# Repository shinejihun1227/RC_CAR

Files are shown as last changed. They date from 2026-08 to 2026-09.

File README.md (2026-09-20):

# RC_CAR · ESP32 RC카 강의 실습

기본 모터 주행부터 거리 감지, 무선 조종, 손 제스처, 2구동륜 PID 속도 제어까지 직접 구현하는 강의용 저장소입니다. **ESP32에 Arduino IDE로 코드를 업로드하고, C언어 문법 중심으로 실습합니다.** 수업에 필요한 코드·배선·부품·설계를 모았습니다.

학생이 작성하는 제어 로직은 변수, 조건문, 반복문, 함수, 배열, 구조체로 구성합니다. `.ino`는 C++로 컴파일되며 `Serial`, `Wire`, 센서 객체는 Arduino 라이브러리의 API를 사용합니다. [C언어 중심 실습 안내](course/ARDUINO_C_GUIDE.md)에서 이 구분과 단계별 과제를 확인합니다.

## v0~v4에서 배우는 것

| 단계 | 결과물 | 코딩 개념 | 주요 부품·하드웨어 |
|---|---|---|---|
| [v0 기본 주행](v0/README.md) | 시리얼 명령으로 움직이는 2WD RC카 | 상수, 함수, 조건문, GPIO, PWM, 시리얼 입력 | ESP32, TB6612FNG 1개, TT 모터 2개 |
| [v1 거리 안전](v1/README.md) | 가까운 장애물 앞에서 전진을 멈추는 차량 | I²C, 라이브러리, 임계값, 상태와 반복 감시 | v0 + VL53L1X |
| [v2 무선 조종](v2/README.md) | 조이스틱으로 제어하는 무선 RC카 | ADC, 데드존, 값 변환, 구조체, 콜백, ESP-NOW | 조종기 ESP32, 조이스틱, 정지 버튼 추가 |
| [v3 제스처 조종](v3/README.md) | 손 기울기로 제어하는 차량 | Roll/Pitch 계산, 평균 보정, 입력 장치 교체 | 조종기에 BMI270 추가, v2 수신기 재사용 |
| [v4 2구동륜 속도 제어](v4/README.md) | 좌우 구동륜 RPM을 보정하고 뒤 수동 바퀴가 따라오는 차량 | 인터럽트, 펄스·RPM, 배열, 시간 간격, PID | 엔코더 N20 2개, 수동 바퀴 2개, TB6612FNG 1개 |

v0~v3은 TT 모터 2개로 기능을 익힙니다. v4에서는 좌우 N20 엔코더 모터 2개와 뒤쪽 수동 바퀴 2개로 구동계를 바꾸며 차량 핀맵도 바뀝니다. v4는 v2 조이스틱 조종기 또는 v3 제스처 조종기를 사용할 수 있습니다.

## 수업 시작

1. [전체 학습 흐름](course/README.md), [C언어 중심 실습 안내](course/ARDUINO_C_GUIDE.md), [설치·업로드 준비](course/setup/README.md)를 확인합니다.
2. [전체 부품표](parts/BOM.md)에서 해당 단계의 부품을 준비합니다.
3. v0부터 README, 배선표, 단품 테스트, 통합 코드를 순서대로 진행합니다.
4. [장비별 설정](course/CONFIGURATION.md)에 따라 MAC 주소, 모터 방향, 엔코더 펄스 수를 설정합니다.
5. [실습 기록 양식](course/LAB_RECORD.md)에 측정값과 결과를 기록합니다.

## 폴더 안내

```text
RC_CAR/
├─ v0/ ... v4/       단계별 설명·배선·시험 절차·Arduino 코드
├─ course/           전체 학습 흐름·설치·설정·실습 기록
├─ parts/            부품 역할·원리·전체 BOM·구매 규격
└─ hardware/         Fusion 360 설계 코드·참조 부품·STL
```

| 자료 | 용도 |
|---|---|
| [부품과 신호](parts/README.md) | ESP32·드라이버·모터·센서의 역할 |
| [부품 작동 원리](parts/PRINCIPLES.md) | 전원, H-브리지·PWM, ToF, IMU, 엔코더·PID |
| [Fusion 360·STL](hardware/README.md) | 실물 치수 확인과 차체·조종기 설계 |
| [Arduino C 실습](course/ARDUINO_C_GUIDE.md) | C 문법 학습 순서·코드 읽기·수정 과제·시리얼 확인 |

차량 전원은 1.5V AA 알카라인 4개(공칭 6V)와 ESP32용 5V 벅-부스트를 기준으로 합니다. 조종기 전원은 1셀 배터리를 보호·충전 회로와 3.3V 정전압 레귤레이터를 거쳐 공급합니다. 모터 전원과 로직 전원을 구분하고 각 장치 안에서 GND를 공통으로 연결합니다. 처음 모터를 시험할 때는 바퀴를 바닥에서 띄웁니다.

## 게시 범위

GitHub에는 강의에서 직접 사용하는 Arduino 코드·배선·부품·설계를 게시합니다. PPT·한글 문서, PC용 Python 시리얼 실습과 제작 중간 자료는 로컬에서 관리합니다. Fusion 360용 Python 생성기는 차체 설계 도구로 유지합니다. 이후에도 적용할 기준은 [AGENTS.md](AGENTS.md)에 기록합니다.

MAC 주소, 엔코더 PPR, PID 계수와 설계 치수는 장비에 맞춰 확인해야 합니다. 컴파일 확인과 실물 주행 시험은 별도로 기록합니다.

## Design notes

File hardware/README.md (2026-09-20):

# 차체·조종기 설계 실습

실제 부품을 측정하고 샤시·브래킷·배터리·전자부품의 장착 공간을 확인하는 자료다. 설계 코드가 실행되는 것과 실물에 맞는 것은 별도로 확인한다.

v4 모터 장착·부품 배치 실습은 좌우 N20 2구동륜과 뒤 수동 바퀴 2개를 기준으로 [실측 부품 기반 Fusion 360 설계 안내](fusion360/MEASURED_PARTS_WORKFLOW.md)에서 시작한다. 불러올 부품별 파일, STEP/STL 선택, 실측 기록, 파라미터와 출력 여유, 시험 출력 순서를 정리했다.

| 수업 | 파일 | 용도 |
|---|---|---|
| 기본 샤시 | [기본 프레임 생성기](fusion360/RC_CAR_Chassis_Frame_Builder.py) | 300×400mm 샤시, 레일, 범퍼, 브리지. [설명](fusion360/CHASSIS_ONLY_README.md) |
| 부품 장착 | [장착 프레임 생성기](fusion360/RC_CAR_Mounting_Frame_Builder.py) | N20 브래킷, 배터리 트레이, 전장 데크, ToF 장착부 |
| 로버형 확장 | [로버 샤시 생성기](fusion360/RC_CAR_Rover_Chassis_Builder.py) | 320×420mm 차체·상부 데크·작업 장치 인터페이스. [설명](fusion360/ROVER_CHASSIS_README.md) |
| 부품 배치 | [참조 부품](reference-parts/README.md) | 모터·바퀴·보드·홀더 외곽 STL와 배치 생성기 |
| 조종기·모터 고정 | [STL 안내](stl/README.md) | 케이스 상·하판과 N20 마운트 |

## 실행 순서

1. 실제 모터·축·장착홀, 보드 USB 위치, 배터리 홀더를 캘리퍼스로 측정한다.
2. Fusion 360의 Scripts and Add-Ins에서 필요한 Python 생성기를 등록·실행한다.
3. 새 Design에서 컴포넌트와 파라미터를 확인한다.
4. 브래킷 또는 홀 시편부터 시험 출력한다.
5. 간섭과 체결을 확인한 뒤 전체 차체에 적용한다.

현재 대형 프레임은 220×220mm급 프린터보다 크다. 프린터에 맞는 크기 변경·분할 등 제작 방식을 먼저 정한다. v0~v3의 소형 TT 실습에 대형 로버 프레임이 필수인 것은 아니다.

장착 프레임은 앞쪽 좌우 N20 브래킷을 기본 표시하고 뒤쪽 수동 바퀴 지지 구역을 별도로 두며 TT 브래킷과 참조 외곽을 숨기는 구성이다. v4에서 모터를 교체할 때 엔코더 PCB·배선 공간과 수동 바퀴의 접지 높이를 확인한다.

[치수 출처와 확인 항목](fusion360/DIMENSION_SOURCES.md)

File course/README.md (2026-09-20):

# 전체 강의 흐름

Arduino IDE에서 C언어 문법 중심으로 코딩하고 ESP32에서 실행한다. 한 단계에서 입력·판단·출력을 이해한 뒤, 다음 단계에서 입력 장치나 피드백을 하나씩 확장한다. [C 문법·수정 과제 안내](ARDUINO_C_GUIDE.md)를 함께 사용한다.

| 단계 | 수업에서 설명할 내용 | 핵심 코드 읽기 | 하드웨어 실습 | 학생 결과물 |
|---|---|---|---|---|
| [v0](../v0/README.md) | ESP32가 방향 신호와 PWM을 만들고 드라이버가 모터를 구동하는 과정 | int, const, 함수·인자, if, switch, setup/loop, GPIO·PWM | 공통 GND, 좌우 모터 연결과 방향 확인 | 시리얼 f/b/l/r/s 주행 |
| [v1](../v1/README.md) | 거리를 숫자로 읽고 전진 허용 여부를 판단하는 과정 | Wire, 센서 초기화, 조건식, millis, 현재 명령 상태 | SDA/SCL과 센서 전원, 거리별 측정 | 20cm 이하 전진 정지 시험 |
| [v2](../v2/README.md) | 조종기 입력을 명령 패킷으로 바꿔 차량에 전달하는 과정 | analogRead, map, 데드존, struct, callback, 시간 초과 | ESP32 2개, 조이스틱, 정지 버튼 | 무선 조종·통신 끊김 정지 시험 |
| [v3](../v3/README.md) | 가속도로 기울기를 추정하고 같은 패킷으로 보내는 과정 | atan2, sqrt, 평균, 중립 오프셋, 각도→명령 변환 | BMI270 I²C 배선과 장착 방향 | 중립·전후·좌우 제스처 시연 |
| [v4](../v4/README.md) | 좌우 구동 모터의 명령과 실제 회전 속도 차이를 보정하는 과정 | ISR, volatile, 임계 구역, 배열, dt, P/I/D | 좌우 모터 독립 구동, CHA 2개, 뒤 수동 바퀴, PPR 실측 | 좌우 RPM 기록·직진 편차 비교 |

## 수업 진행 방식

1. 부품 하나의 역할과 신호를 설명한다.
2. 전원을 끈 상태에서 배선하고 단품 읽기/구동 코드를 업로드한다.
3. 시리얼 출력과 실제 동작을 비교한다.
4. 기존 동작에 새 기능을 연결한다.
5. 실패 상황도 시험하고 결과를 기록한다.

v0의 간단한 주행이 v1의 안전 판단을 이해하는 출발점이다. v2에서는 입력이 PC에서 무선 조종기로 바뀐다. v3는 차량을 바꾸기보다 조종기 입력을 교체하는 실습이다. v4는 차량 구동계와 제어 방식을 바꾸는 단계다.

## 공통 준비

- [설치·업로드](setup/README.md)
- [장비별 설정값](CONFIGURATION.md)
- [부품표](../parts/BOM.md)와 각 버전의 배선표
- [실습 기록](LAB_RECORD.md)
- [샤시 설계](../hardware/README.md): 실제 부품 외곽과 장착홀을 측정한 뒤 진행

## Arduino 시리얼 모니터로 확인하기

아래 실습은 Arduino IDE의 시리얼 모니터를 115200 baud로 열어 진행한다. 별도 PC 프로그램 설치 없이 센서 값과 명령을 확인한다.

| 연결 단계 | 업로드할 Arduino 스케치 | 확인할 내용 |
|---|---|---|
| v1 거리 단품 | [01_distance_read](../v1/firmware/01_distance_read/01_distance_read.ino) | distance_mm 값과 실제 거리 비교 |
| v1 안전 주행 | [02_safety_stop](../v1/firmware/02_safety_stop/02_safety_stop.ino) | 입력창에서 f/b/l/r/s를 전송하고 전진 정지 확인 |
| v3 센서 단품 | [00_bmi270_read](../v3/firmware/00_bmi270_read/00_bmi270_read.ino) | 가속도·자이로 값의 축과 단위 |
| v3 제스처 판정 | [01_gesture_map_test](../v3/firmware/01_gesture_map_test/01_gesture_map_test.ino) | Roll/Pitch와 STOP/FORWARD/BACKWARD/LEFT/RIGHT |
| v4 엔코더 단품 | [00_encoder_read](../v4/firmware/00_encoder_read/00_encoder_read.ino) | 좌우 구동륜의 펄스 수와 RPM 기록 |
| v4 PID 조정 | [01_speed_pid_tune](../v4/firmware/01_speed_pid_tune/01_speed_pid_tune.ino) | f/b/s와 +/- 명령으로 목표 RPM과 실제 RPM 비교 |

v3 제스처 판정 단품은 원시 가속도로 각도를 계산한다. v3 통합 조종기는 부팅 시 100회 평균으로 중립을 보정하므로 둘의 출력 기준을 구분해서 설명한다. 측정값은 [실습 기록](LAB_RECORD.md)에 적는다.

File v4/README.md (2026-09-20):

# v4 · 엔코더 N20 2구동륜 PID 제어

좌우 N20 엔코더 모터 2개의 회전 속도를 측정하고 목표 RPM과의 차이를 PWM으로 보정한다. 뒤쪽 2바퀴는 자유회전 수동 바퀴다.

## 배우는 코딩

Arduino IDE에서 C 문법 중심으로 진행한다. [단계별 문법·수정 과제](../course/ARDUINO_C_GUIDE.md)를 함께 사용한다.

인터럽트에서 좌우 CHA 상승 에지를 센다. 임계 구역으로 카운터를 복사하고 펄스 수·측정 시간·PPR로 RPM을 계산한다. 배열과 반복문으로 구동 모터 2개를 처리하며 P/I/D와 trim으로 출력을 보정한다. 수동 바퀴에는 모터나 엔코더를 연결하지 않는다. 엔코더는 CHA만 읽으므로 회전 방향을 직접 측정하지 않는다.

## 하드웨어와 부품

엔코더 N20 2개, 자유회전 수동 바퀴 2개, N20 브래킷 2개, TB6612FNG 1개를 사용한다. VL53L1X와 조종기는 재사용한다. v0 핀맵을 그대로 쓰지 않는다. GPIO 34/35는 엔코더 입력이며 필요한 경우 외부 풀업을 사용한다.

[배선표](docs/wiring.md) · [전원 시스템 검토](docs/power-analysis.md) · [단계별 부품표](docs/bom.md) · [구매 규격](../parts/purchasing/v4.md) · [부품 원리](../parts/PRINCIPLES.md)

차체와 모터 마운트는 [실측 부품 기반 Fusion 360 설계 안내](../hardware/fusion360/MEASURED_PARTS_WORKFLOW.md)에 따라 부품 외곽·축·장착홀을 확인하고 한 개를 시험 출력한 뒤 제작한다.

## 실습 순서

[설치 안내](../course/setup/README.md)를 확인하고 표의 순서대로 각 스케치를 별도로 업로드한다.

| 스케치 | 실습 내용 |
|---|---|
| [00_encoder_read](firmware/00_encoder_read/00_encoder_read.ino) | 좌우 구동륜 펄스·RPM, 출력축 PPR 실측 |
| [01_speed_pid_tune](firmware/01_speed_pid_tune/01_speed_pid_tune.ino) | f/b/s와 +/-로 목표 RPM·PID 시험 |
| [vehicle_encoder_receiver](firmware/vehicle_encoder_receiver/vehicle_encoder_receiver.ino) | v2 또는 v3 조종기·전진 거리 정지·좌우 2모터 PID 통합 |

[PID 튜닝 순서](docs/pid-tuning.md)를 따르고, 튜닝 코드에서 확인한 PPR·PID·trim 값을 통합 수신기에도 반영한다.

## 확인할 결과

세 스케치의 PPR 기본값 1.0을 좌우 구동륜 실측값으로 바꾼다. 바퀴를 띄워 방향·RPM을 확인하고 저속 직진 편차를 비교한다. PID·trim 기본값은 실물 튜닝 완료값이 아니다. 수동 바퀴가 바닥에 고르게 닿고 구동 바퀴와 같은 접지 높이를 갖는지 별도로 확인한다.

[요구사항](docs/requirements.md) · [시험 절차](docs/test-plan.md) · [장비 설정](../course/CONFIGURATION.md) · [실습 기록](../course/LAB_RECORD.md)

## 다음 단계

CHB 방향 측정, 속도 기록, 주행 편차 분석을 선택 확장으로 진행한다.

[전체 학습 흐름](../course/README.md)

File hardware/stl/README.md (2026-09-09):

# 조종기·모터 장착 STL

| 파일 | 사용하는 실습 | 확인할 것 |
|---|---|---|
| [controller-top.STL](controller-top.STL) | v2 조이스틱 조종기 케이스 상판 | 조이스틱·버튼 구멍, ESP32 USB 공간 |
| [controller-bottom.STL](controller-bottom.STL) | v2 조종기 케이스 하판, v3 배치 검토 | 보드 고정·배선·BMI270 추가 공간 |
| [N20withEncoder_mount.stl](N20withEncoder_mount.stl) | v4 N20 모터 장착 | 모터 폭·고정홀·엔코더 PCB·축 높이 |

기존 강의 작업 폴더에 보관되어 있던 파일이다. 부품 모델명과 실제 치수를 대조하고 한 개를 시험 출력한 뒤 적용한다. 참조 부품 폴더의 외곽 STL는 이 파일들과 용도가 다르다.

외부 모델을 사용할 때는 원 출처의 사용 조건을 따른다. 기존 프로젝트의 조종기 참고 출처는 [Wallieonline ESP-NOW 조종기](https://www.wallieonline.nl/blogs/esp-now-remote-control-mini-robots.html)와 [케이스 자료](https://makerworld.com/en/models/695669#profileId-624636)이며, 참고 링크만으로 각 로컬 STL의 원 저작자나 라이선스를 단정하지 않는다.

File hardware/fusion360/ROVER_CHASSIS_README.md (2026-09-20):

# RC_CAR 로버형 샤시

MakerWorld의 [RC Rover with Robot Arm 6 DOF](https://makerworld.com/ko/models/1342319-rc-rover-with-robot-arm-6-dof#profileId-1383072)의 전체 STL을 복사한 파일이 아닙니다. 해당 모델에서 보이는 로버형 레이어 구조를 참고하여, 현재 프로젝트의 N20/TT 공통 장착 방향에 맞춘 Fusion 360 네이티브 파라미터 모델입니다.

## 실행 파일

`RC_CAR_Rover_Chassis_Builder.py`

Fusion 360에서 `Utilities → Add-Ins → Scripts and Add-Ins`를 열고 이 파일을 선택한 뒤 `Run`을 누릅니다.

## 생성되는 구조

```text
RC_CAR_ROVER_CHASSIS
├─ 01_ROVER_Lower_Tub_Plate
├─ 01_ROVER_Left/Right_Raised_Side_Rail
├─ 01_ROVER_Front/Rear_Bumper_Beam
├─ 02_ROVER_Motor_Interface_Pad_FL/FR + Passive_Wheel_Support_RL/RR
├─ 03_ROVER_Upper_Deck_Post_FL/FR/RL/RR
├─ 03_ROVER_Upper_Electronics_Deck
└─ 04_ROVER_Arm_Base_Interface
```

모터나 바퀴를 모델 안에 집어넣지 않았습니다. 대신 앞쪽 좌우 `Motor_Interface_Pad`에는 N20 브래킷을, 뒤쪽 좌우에는 실제 수동 바퀴에 맞춘 축·캐스터 지지부를 M3 체결로 장착하는 방식입니다. 즉, 이 파일에서 먼저 확인할 것은 차체의 비율과 체결 공간입니다.

## 기본 크기

| 항목 | 값 |
|---|---:|
| 하부 차체 | 320 × 420 × 6 mm |
| 하부 서비스 개구부 | 150 × 260 mm |
| 좌우 레일 | 8 × 370 × 36 mm |
| 앞뒤 범퍼 | 290 × 12 × 32 mm |
| 모터 어댑터 패드 | 82 × 28 × 8 mm, 2개(좌우 N20 구동) |
| 패드 M3 홀 패턴 | 50 × 14 mm 중심 간격 |
| 상부 데크 | 280 × 250 × 5 mm |
| 작업 장치 패드 | Ø126 × 6 mm |

320 × 420 mm는 링크 모델처럼 큰 로버 느낌을 내기 위한 기준입니다. 220 × 220 mm급 프린터로 한 번에 출력하기에는 크므로, 실제 제작은 알루미늄/아크릴 판재로 가공하거나 하부 차체를 2~4개로 분할하는 방식을 권장합니다.

## 링크 모델에서 참고한 부분

링크의 설명에는 차체와 6축 암을 통합한 구조, 37 mm 감속 모터, 608 베어링, M8 축, 여러 길이의 M3 체결재가 제시되어 있습니다. 이 모델의 특징을 그대로 복제하지 않고 다음 설계 원칙만 반영했습니다.

- 하부 차체와 상부 데크를 분리
- 좌우 구동부를 수용할 높은 측면 레일
- 상부 중앙의 작업 장치 장착 인터페이스
- 정비·배선을 위한 중앙 개구부
- 모터를 직접 고정하지 않고 교체 가능한 어댑터 패드 사용

원본 MakerWorld 페이지의 라이선스는 `Standard Digital File License`로 표시되므로, 원본 STL을 프로젝트에 복사하지 않고 구조적 아이디어만 참고했습니다. [원본 모델](https://makerworld.com/ko/models/1342319-rc-rover-with-robot-arm-6-dof#profileId-1383072)과 [모델 정보 미러](https://www.3dgo.app/models/makerworld/1342319)

## 변경할 때 주의할 점

`Modify → Change Parameters`에서 판 두께와 데크 두께는 먼저 조정할 수 있습니다. 전체 폭·길이를 크게 바꾸거나 포스트 위치를 변경할 때는 파라미터를 바꾼 뒤 스크립트를 다시 실행하는 편이 안전합니다. 발생 위치가 발생학적으로 모두 연결된 단일 스케치가 아니라, 읽기 쉬운 부품별 컴포넌트로 나뉘어 있기 때문입니다.

앞쪽 N20 호환은 두 개의 패드에 실제 브래킷을 고정하는 설계입니다. 뒤쪽 수동 바퀴 지지부와 모터의 실제 고정홀, 축 중심 높이, 바퀴 지름을 확인하기 전에는 형상을 직접 결합하지 않습니다.

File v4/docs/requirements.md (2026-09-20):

# v4 요구사항

- 차량은 6 V, 100 RPM급 엔코더 포함 N20 메탈 기어드모터 2개와 자유회전 수동 바퀴 2개를 사용한다.
- 좌우 N20 모터는 TB6612FNG 한 개의 A/B 채널에 각각 연결한다.
- 각 구동 모터는 엔코더 A 채널 1개로 속도를 측정한다. 방향은 모터 명령에서 알 수 있으므로 첫 실습에서는 B 채널을 연결하지 않는다.
- 좌우 2개의 구동 모터 속도를 각각 PID로 제어한다. 수동 바퀴는 속도 피드백 대상이 아니다.
- v1의 거리 안전 정지와 v2의 통신 끊김 자동 정지는 최우선으로 동작한다.

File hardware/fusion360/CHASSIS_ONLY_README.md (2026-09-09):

# RC_CAR 샤시 먼저 만들기

## 이 파일의 목적

`RC_CAR_Chassis_Frame_Builder.py`는 모터나 전자부품을 얹기 전에 **샤시 프레임 자체의 구조와 크기만 확인하는 첫 단계**입니다.

이 스크립트는 다음 구조만 만듭니다.

```text
RC_CAR_CHASSIS_ONLY
├─ 01_CHASSIS_Base_Plate
├─ 01_CHASSIS_Left_Side_Rail
├─ 01_CHASSIS_Right_Side_Rail
├─ 01_CHASSIS_Front_Bumper
├─ 01_CHASSIS_Rear_Bumper
├─ 02_CHASSIS_Mounting_Bridge_Front
├─ 02_CHASSIS_Mounting_Bridge_Center
├─ 02_CHASSIS_Mounting_Bridge_Rear
├─ 03_CHASSIS_Deck_Post_FL/FR/RL/RR
└─ 99_CHASSIS_Rigid_Structure
```

모터, 바퀴, ESP32, TB6612FNG, 배터리, 센서, 저장소의 STL 파일은 이 단계에서 생성하거나 삽입하지 않습니다. 따라서 화면에서 무엇이 샤시인지 바로 구분할 수 있습니다.

## 기본 설계값

| 항목 | 기본값 | 역할 |
|---|---:|---|
| 전체 폭 × 길이 | 300 × 400 mm | 대형 RC카 기준 외곽 |
| 하부 플레이트 | 5 mm | 주 구조판 |
| 중앙 개구부 | 140 × 240 mm | 무게 감소 및 배선 공간 |
| 좌우 레일 | 8 × 380 × 24 mm | 비틀림 보강 및 측면 결속 |
| 앞뒤 범퍼 | 270 × 12 × 28 mm | 끝단 보호 및 가로 보강 |
| 장착 브리지 | 3개, 폭 260 mm | 이후 N20/TT 브래킷을 고정할 구조 |
| 상부 데크 포스트 | Ø10 × 22 mm, 4개 | 나중에 상부 프레임을 올릴 지지점 |
| 기본 나사 구멍 | Ø3.4 mm | M3 관통 여유홀 시작값 |

실제 출력에서는 소재, 프린터, 나사 종류에 따라 구멍 여유를 시험해야 합니다. 위 값은 완성품 치수를 보장하는 값이 아니라 첫 설계 검토용 기준값입니다.

## Fusion 360에서 실행하는 순서

1. `Utilities → Add-Ins → Scripts and Add-Ins`를 엽니다.
2. `My Scripts`에서 `RC_CAR_Chassis_Frame_Builder.py`를 선택합니다.
3. `Run`을 누릅니다.
4. Browser에서 `RC_CAR_CHASSIS_ONLY` 아래 구조를 확인합니다.
5. `Modify → Change Parameters`에서 `chassis_width`, `chassis_length`, `central_opening_width` 등을 바꿔봅니다.

이번 단계에서는 기존의 `RC_CAR_Mounting_Frame_Builder.py`를 실행하지 않습니다. 그 파일은 이후 모터·전자부품 장착 위치까지 검토하는 조립 단계용입니다.

## 왜 이런 구조로 시작했는가

- [Motor Mash](https://github.com/rbricheno/motor-mash)는 N20을 TT 샤시 계열로 확장하는 측면 클램프, 축 중심, 배선 통로를 보여줍니다. 그래서 이 모델은 모터 형상을 샤시에 박아 넣지 않고, 나중에 교체 가능한 브리지와 브래킷을 받을 수 있게 했습니다.
- [Cubie-3 STL 구조](https://www.kevsrobots.com/projects/cubie-3/stl)는 별도 베이스, 상부 선반, 포스트, 모터 홀더를 분리합니다. 그래서 하부 샤시와 상부 프레임을 처음부터 하나의 덩어리로 만들지 않았습니다.
- [TT motor mounting](https://github.com/grimmpp/tt-motor-mounting)은 TT 모터용 브리지와 베이스를 별도 부품으로 나누는 방식을 참고했습니다. 이 프로젝트의 형상을 복사한 것이 아니라, 교체 가능한 결속부라는 원칙만 반영했습니다.

스크립트는 위 예시의 메시/STL을 그대로 가져오지 않고, Fusion 360의 스케치 → 돌출 → 절삭 → 필렛 순서로 샤시 구조를 새로 만듭니다. 따라서 이후 파라미터를 바꾸거나 피처를 직접 수정할 수 있습니다.

## 처음부터 전체 출력하지 않기

300 × 400 mm는 큰 프레임이므로 220 × 220 mm급 프린터라면 전체 출력 전에 다음만 먼저 확인하는 것이 안전합니다.

1. 장착 브리지 1개를 짧은 시편으로 출력합니다.
2. M3 나사가 통과하는지 확인합니다.
3. 프레임 재료와 두께를 결정합니다.
4. 그다음 전체 샤시를 분할하거나 가공 가능한 판재로 제작합니다.

N20과 TT 모터의 실제 고정홀 위치가 확정되면, 다음 단계에서 이 브리지 위에 **별도 모터 브래킷 컴포넌트**를 추가합니다. 샤시 파일을 먼저 고정해 두면 모터 모델 때문에 기본 프레임이 계속 흔들리는 일을 줄일 수 있습니다.

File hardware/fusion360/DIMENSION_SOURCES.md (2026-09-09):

# 장착 프레임 치수 기준

이 설계는 실제 구매품의 최종 도면이 아니라, 저장소 부품표와 현재 보유한 STL의 외곽 치수를 바탕으로 만든 편집 가능한 기준 모델입니다.

## 저장소 STL 바운딩 박스

| 파일 | 읽은 크기 | 모델에서의 용도 |
|---|---:|---|
| `hardware/stl/controller-bottom.STL` | 약 `137.326 × 25 × 80.932 mm` | 눕혀 놓은 컨트롤러 reference box |
| `hardware/stl/controller-top.STL` | 약 `137.326 × 21 × 80.932 mm` | 컨트롤러 상부 reference box |
| `hardware/stl/N20withEncoder_mount.stl` | 약 `27 × 12 × 27.5 mm` | N20 마운트 외곽 reference box |

현재 원격 저장소에는 이 STL 파일 자체가 없으므로, Python 스크립트에는 STL 메시를 복제하지 않고 위 바운딩 박스 치수만 파라미터로 기록했습니다. 실제 STL을 다시 복사한 뒤 Fusion에서 `Insert Mesh`로 확인할 수 있습니다.

## 모터 기준

### N20 엔코더 모터

- 본체 기준: 약 `12 × 10 × 32.5 mm`
- 출력축: `Ø3 mm`, 길이 약 `9 mm`
- 기본 장착판: `90 × 64 × 5 mm`
- 공통 체결홀: X `±30 mm`, Y `±24 mm`
- 오픈 클램프: 길이 `40 mm`, 내부 폭은 모터 폭과 `fit_clearance` 기준

### TT 기어드모터

- 본체 기준: 약 `70 × 22 × 19 mm`
- 출력축 기준: 약 `Ø5.3 mm`, 길이 `10 mm`
- 기본 장착판: `100 × 72 × 5 mm`
- 공통 체결홀: N20과 동일한 X `±30 mm`, Y `±24 mm`
- 오픈 크래들: 길이 `74 mm`, TT 외형 폭 기준

TT 제품은 제조사와 감속비에 따라 외형이 달라질 수 있으므로 기본 숨김 교체 옵션입니다.

## 최종 실측이 필요한 항목

- N20 엔코더 PCB까지의 전체 길이와 커넥터 방향
- N20 브래킷의 실제 고정홀 간격
- TT 모터의 본체 및 축 높이
- 바퀴 허브의 실제 축 형상(D축/원형)과 내경
- 4×AA 홀더의 외곽과 나사 위치
- ESP32 USB 포트 및 TB6612FNG 모듈의 실제 홀 위치

금속 가공 공차를 그대로 적용하지 않고, FDM 출력에서는 `fit_clearance = 0.4 mm`부터 시험합니다.

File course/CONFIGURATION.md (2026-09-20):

# 실습 장비별 설정

아래 값은 수업 전에 장비에서 확인한다. 저장소의 기본값을 실제 보정 결과로 간주하지 않는다.

| 항목 | 위치 | 설정 방법 |
|---|---|---|
| ESP32 보드·포트 | Arduino IDE | ESP32 Dev Module과 해당 USB 포트 선택 |
| 차량 MAC | v2 송신 시험·조이스틱, v3 BMI270 송신 코드의 vehicleMac | v2/firmware/00_print_mac으로 차량 STA MAC 확인 |
| 조이스틱 중심·방향 | v2 controller_joystick | 기본 중심 2048, 데드존 120. 손을 떼었을 때 0인지 확인 |
| BMI270 중립 | v3 controller_bmi270 | 부팅 시 100회 평균 동안 조종기를 움직이지 않음 |
| 기울기 크기 | v3 controller_bmi270 | 기본 데드존 8°, 최대 명령 각도 35° |
| 모터 방향 | 버전별 모터 함수와 배선 | 좌우 N20 구동축 한 개씩 확인. 뒤 수동 바퀴에는 신호를 연결하지 않음 |
| 바퀴 1회전당 펄스 | v4 스케치 3개의 PULSES_PER_WHEEL_REV | CHA 상승 에지 기준으로 실측. 기본값 1.0은 미보정 표시 |
| PID·trim | v4 속도 튜닝·통합 수신기 | 같은 장비에서 측정한 계수와 모터별 보정값을 두 코드에 반영 |
| 차체·홀·간섭 치수 | hardware/fusion360 | 실제 모터·보드·홀더·바퀴를 측정 |

## 전원 설정

차량은 1.5V AA 4개를 TB6612FNG의 VM에 연결하고, 같은 배터리에서 5V 벅-부스트를 거쳐 차량 ESP32의 5V/VIN에 공급한다. 조종기 ESP32와 BMI270은 별도 1셀 배터리를 보호·충전 회로와 3.3V 레귤레이터를 거친 출력에 연결한다. 일반 Li-ion 셀을 생으로 ESP32의 3V3 핀에 연결하지 않는다.

## 전진 안전 판단

v1 안전 주행과 v2·v4 차량 수신기는 거리 200mm 이하에서 전진을 차단한다. 유효한 거리값이 없거나 최근 측정이 250ms 넘게 갱신되지 않아도 전진을 차단한다. 후진·제자리 회전은 장애물에서 빠져나오는 동작으로 허용한다.

v1의 500mm 이내 경고는 시리얼 알림이다. 자동 감속 기능은 기본 코드에 포함하지 않는다. v2·v4는 수신 중단을 300ms 기준으로 판단하고 정지 버튼 명령도 우선 처리한다. 실제 정지 지연은 루프 실행 시간, 센서·I²C 상태와 실물 관성의 영향을 받으므로 테스트 계획대로 측정한다.

## 엔코더 실측

00_encoder_read는 500ms 구간별 펄스를 출력한다. 바퀴를 한 바퀴 돌리는 동안의 구간 펄스를 더해 출력축 한 바퀴의 PPR을 구한다. 마지막 구간을 빠뜨리지 않도록 정지 후 출력까지 확인한다.

CHA만 읽으므로 실제 회전 방향은 측정하지 않는다. 회전 방향은 모터에 내린 명령을 기준으로 사용한다. CHB를 이용한 방향 측정은 확장 실습이다.

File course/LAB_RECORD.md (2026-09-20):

# 실습 기록 양식

팀/이름: __________  날짜: __________  버전: __________

| 확인 항목 | 기록 |
|---|---|
| ESP32 보드·보드 패키지 버전 | |
| 라이브러리 이름·버전 | |
| 업로드한 송신기/수신기 스케치 | |
| 배선표와 달라진 GPIO | |
| 사용 모터·감속비·바퀴 지름 | |
| 엔코더 PPR과 집계 방식 | |
| PID 계수·모터별 trim | |
| 차량 배터리·VM 전압 / ESP32 5V 측정값 | |
| 조종기 셀 종류·충전기·3.3V 레일 측정값 | |

| 단계 | 시험 | 예상 결과 | 실제 결과·측정값 | 통과 여부 |
|---|---|---|---|---|
| v0 | 전원 투입, f/b/l/r/s | 임의 주행 없음, 방향·정지 일치 | | |
| v1 | f 한 번 입력 후 장애물 접근 | 새 키 입력 없이 전진 정지 | | |
| v1 | 정지 거리 경계·센서 분리 | 200mm 이하 또는 측정 실패 시 전진 차단 | | |
| v2 | 조종기 전원 끄기·정지 버튼 | 수신 시간 초과·정지 명령에 정지 | | |
| v3 | 중립·전후·좌우 기울기 | 의도한 명령 생성, 중립 정지 | | |
| v4 | 좌우 RPM·1m 직진 3회 | 좌우 속도 편차·직진 편차 측정 | | |

문제 원인: __________

바꾼 설정 또는 코드: __________

변경 전후 결과: __________

다음 실습에서 확인할 것: __________

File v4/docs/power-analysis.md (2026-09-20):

# v4 전원 시스템 검토

## 제안 구성

```text
차량: 1.5 V AA × 4 (공칭 6 V)
  ├─ 스위치·퓨즈 ── TB6612FNG VM ── 좌우 6 V N20 모터 2개
  └─ 5 V 벅-부스트 ── 차량 ESP32 5V/VIN

조종기: 1셀 Li-ion/LiPo
  └─ 보호·충전 회로 ── 3.3 V 레귤레이터 ── 조종기 ESP32·BMI270
```

차량의 4×AA는 공칭 6 V이므로 6 V N20의 모터 전원 후보로 사용할 수 있다. TB6612FNG의 VM 허용 범위 안에 있지만, 실제 사용 가능 여부는 구매한 N20의 정지전류와 AA 셀의 순간 전류에 달려 있다. TB6612FNG의 데이터시트 정격은 평균 출력 전류 1.2 A, 피크 3.2 A이므로 이 수치를 모터 정지전류와 비교한다. [Toshiba TB6612FNG 데이터시트](https://toshiba.semicon-storage.com/info/TB6612FNG_datasheet_en_20141001.pdf?did=10660&prodName=TB6612FNG)

차량 ESP32에는 AA 팩을 직접 연결하지 않는다. 5 V 벅-부스트의 출력 전압을 USB를 연결하기 전에 측정하고, 모터 기동 때도 5 V가 유지되는지 확인한다. ESP32 모듈의 권장 동작 전압은 3.0~3.6 V이며 전원은 최소 500 mA 이상의 여유를 갖도록 설계한다. [Espressif ESP32 하드웨어 설계 지침](https://docs.espressif.com/projects/esp-hardware-design-guidelines/en/latest/esp32/schematic-checklist.html)

## 조종기 1셀 전원 주의

일반 Li-ion/LiPo 1셀은 공칭 약 3.6~3.7 V이고 완충 시 4.2 V가 된다. 따라서 원셀을 ESP32의 `3V3` 핀에 직접 연결하면 안 된다. 보호·충전 회로를 사용하고, 충전기와 셀 화학계열을 일치시킨 뒤, 3.3 V로 조정된 buck-boost 또는 충분한 입력 범위의 레귤레이터를 거친 출력만 ESP32와 BMI270에 공급한다. 만약 실제 셀이 LiFePO4라면 공칭 전압과 완충 전압이 다르므로 LiFePO4 전용 충전기와 해당 입력 범위의 레귤레이터를 사용한다. [Panasonic 산업용 배터리 카탈로그](https://energy.panasonic.com/dam/master/pdf/eu/catalog/old/Panasonic_Industrial-Batteries-For-Professionals_Short-Form-Catalog.pdf)

BMI270의 VDD/VDDIO 범위는 1.7~3.6 V이므로 3.3 V 레일과 맞는다. 전원 설계에서 더 큰 순간 전류 여유가 필요한 쪽은 BMI270보다 ESP32 무선 송신부다. [Bosch BMI270 제품 페이지](https://www.bosch-sensortec.com/en/products/motion-sensors/imus/bmi270)

## 결론과 확인 조건

- 차량 쪽 4×AA + TB6612FNG + 5 V 벅-부스트 구조는 조건부로 적합하다.
- 조종기 쪽은 “3.3 V 리튬이온 셀”이라고 부르지 말고, `1셀 배터리 + 보호·충전 + 3.3 V 레귤레이터 출력`으로 부품을 지정한다.
- 실제 구매 전 N20 정지전류, 엔코더 출력 전압, AA 셀 종류, 레귤레이터의 입력 범위와 출력 전류를 기록한다.
- 첫 전원 시험은 모터를 공중에 띄운 상태에서 한다. 모터 기동·정지 때 차량 5 V와 조종기 3.3 V를 측정하고, TB6612FNG와 배터리 홀더의 발열을 기록한다.
- 수동 바퀴의 접지 높이와 자유회전을 확인한다. 바퀴가 걸리거나 차체 하중을 과도하게 받으면 모터 정지전류가 증가한다.

이 문서는 부품 실측과 전기 시험 전의 설계 검토다. 시험 전에는 “전원 시스템 검증 완료”로 표현하지 않는다.

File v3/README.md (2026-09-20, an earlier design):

# v3 · BMI270 손 제스처 조종

손 조종기의 기울기를 전진·후진·조향 명령으로 변환한다.

## 배우는 코딩

Arduino IDE에서 C 문법 중심으로 진행한다. [단계별 문법·수정 과제](../course/ARDUINO_C_GUIDE.md)를 함께 사용한다.

단품 실습에서는 가속도와 자이로를 모두 읽는다. 현재 조종기의 Roll/Pitch 계산은 가속도에 atan2·sqrt를 적용한다. 부팅 시 100회 평균으로 중립을 보정하고, 8° 미만 데드존과 35° 최대 명령 범위를 적용한다. 자이로 융합·절대 Yaw 제어는 기본 구현에 없다.

## 하드웨어와 부품

v2의 조종기 ESP32를 재사용하고 BMI270 1개를 추가한다. SDA/SCL은 GPIO 21/22, 정지 버튼은 GPIO 4다. ESP32를 세 번째로 추가하지 않는다.

[배선표](docs/wiring.md) · [단계별 부품표](docs/bom.md) · [구매 규격](../parts/purchasing/v3.md) · [부품 원리](../parts/PRINCIPLES.md)

## 실습 순서

[설치 안내](../course/setup/README.md)를 확인하고 표의 순서대로 각 스케치를 별도로 업로드한다.

| 스케치 | 실습 내용 |
|---|---|
| [00_bmi270_read](firmware/00_bmi270_read/00_bmi270_read.ino) | 가속도 g·각속도 dps 출력 |
| [01_gesture_map_test](firmware/01_gesture_map_test/01_gesture_map_test.ino) | Roll/Pitch와 STOP/FORWARD/BACKWARD/LEFT/RIGHT 비교 |
| [controller_bmi270](firmware/controller_bmi270/controller_bmi270.ino) | 중립 보정 후 기울기를 ESP-NOW 명령으로 송신 |

차량에는 [v2 vehicle_receiver](../v2/firmware/vehicle_receiver/vehicle_receiver.ino)를 업로드한다. [제스처 맵](docs/gesture-map.md)에서 단품 판정과 통합 조종기의 차이를 확인한다.

## 확인할 결과

부팅 중 조종기를 고정하고, 중립·기울기·정지 버튼·통신 끊김을 시험한다. 센서 장착 방향에 따라 각도 부호를 실제 동작과 비교한다.

[요구사항](docs/requirements.md) · [시험 절차](docs/test-plan.md) · [장비 설정](../course/CONFIGURATION.md) · [실습 기록](../course/LAB_RECORD.md)

## 다음 단계

v4에서 차량을 좌우 엔코더 N20 2구동륜과 뒤쪽 수동 바퀴 2개 구조로 교체한다.

[전체 학습 흐름](../course/README.md)

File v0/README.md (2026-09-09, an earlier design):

# v0 · 기본 모터 주행

ESP32가 좌우 모터의 방향과 속도를 제어하고 시리얼 명령으로 차를 움직인다.

## 배우는 코딩

Arduino IDE에서 C 문법 중심으로 진행한다. [단계별 문법·수정 과제](../course/ARDUINO_C_GUIDE.md)를 함께 사용한다.

`const int`로 핀과 속도를 정의한다. 함수를 이용해 모터 한 개의 동작을 묶고, `if`로 모터 방향을 판단하며 `switch`로 시리얼 명령을 해석한다. GPIO 디지털 출력은 방향을, PWM은 구동 세기를 결정한다.

## 하드웨어와 부품

ESP32 1개, TB6612FNG 1개, TT 모터·바퀴 각 2개, AA 4개, 5V 벅-부스트. 모터는 ESP32 GPIO가 아닌 드라이버 출력에 연결한다.

[배선표](docs/wiring.md) · [단계별 부품표](docs/bom.md) · [구매 규격](../parts/purchasing/v0.md) · [부품 원리](../parts/PRINCIPLES.md)

## 실습 순서

[설치 안내](../course/setup/README.md)를 확인하고 표의 순서대로 각 스케치를 별도로 업로드한다.

| 스케치 | 실습 내용 |
|---|---|
| [01_motor_test](firmware/01_motor_test/01_motor_test.ino) | 좌우 모터를 함께 전진·정지·후진·정지시켜 방향 확인 |
| [02_basic_drive](firmware/02_basic_drive/02_basic_drive.ino) | f/b/l/r/s 시리얼 명령으로 전후진·회전·정지 |

## 확인할 결과

단품 테스트는 업로드 후 전후진을 자동 반복하므로 바퀴를 띄워 확인한다. 기본 주행 코드는 전원 투입 후 명령을 기다리며, 다섯 명령이 의도대로 동작하는지 확인한다.

[요구사항](docs/requirements.md) · [시험 절차](docs/test-plan.md) · [장비 설정](../course/CONFIGURATION.md) · [실습 기록](../course/LAB_RECORD.md)

## 다음 단계

v1에서 차량 앞의 거리를 읽고 전진 허용 여부를 판단한다.

[전체 학습 흐름](../course/README.md)

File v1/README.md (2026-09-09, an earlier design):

# v1 · 거리 감지와 안전 정지

VL53L1X 거리값을 읽고 장애물이 가까워지면 전진을 차단한다.

## 배우는 코딩

Arduino IDE에서 C 문법 중심으로 진행한다. [단계별 문법·수정 과제](../course/ARDUINO_C_GUIDE.md)를 함께 사용한다.

Wire와 센서 라이브러리로 I²C 장치를 초기화한다. mm 단위 값을 임계값과 비교한다. 현재 명령을 저장하고 loop에서 센서를 반복 감시하여 키 입력이 없어도 상태를 갱신한다.

## 하드웨어와 부품

v0 차량 + VL53L1X 1개. 센서 SDA는 GPIO 21, SCL은 GPIO 22, 전원은 3.3V 호환 모듈 기준이다.

[배선표](docs/wiring.md) · [단계별 부품표](docs/bom.md) · [구매 규격](../parts/purchasing/v1.md) · [부품 원리](../parts/PRINCIPLES.md)

## 실습 순서

[설치 안내](../course/setup/README.md)를 확인하고 표의 순서대로 각 스케치를 별도로 업로드한다.

| 스케치 | 실습 내용 |
|---|---|
| [01_distance_read](firmware/01_distance_read/01_distance_read.ino) | 단독 거리 출력과 측정 실패 확인 |
| [02_safety_stop](firmware/02_safety_stop/02_safety_stop.ino) | 시리얼 주행에 반복 거리 감시와 전진 정지 결합 |

## 확인할 결과

f를 한 번만 입력한 뒤 장애물을 접근시켜도 멈춰야 한다. 200mm 이하와 측정 불가 시 전진을 차단한다. 500mm 이내 경고는 출력만 하며 자동 감속은 없다. 장애물 정지 후에는 새로운 f 명령으로 재출발한다.

[요구사항](docs/requirements.md) · [시험 절차](docs/test-plan.md) · [장비 설정](../course/CONFIGURATION.md) · [실습 기록](../course/LAB_RECORD.md)

## 다음 단계

v2에서 PC 명령 대신 조이스틱 무선 명령을 받는다.

[전체 학습 흐름](../course/README.md)

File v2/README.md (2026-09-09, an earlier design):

# v2 · 조이스틱 무선 조종

별도 ESP32 조종기에서 차량으로 주행 명령을 전송한다.

## 배우는 코딩

Arduino IDE에서 C 문법 중심으로 진행한다. [단계별 문법·수정 과제](../course/ARDUINO_C_GUIDE.md)를 함께 사용한다.

ADC 값 0~4095를 전후진·조향 명령 -255~255로 변환한다. 데드존으로 중립 흔들림을 줄인다. struct에 명령을 묶어 ESP-NOW로 보내고, 수신 콜백과 loop 사이에서 최근 명령을 공유한다. 수신 시간 초과를 millis로 판단한다.

## 하드웨어와 부품

차량과 조종기에 ESP32 각 1개. 조이스틱 VRx/VRy는 조종기 GPIO 34/35, 정지 버튼은 GPIO 4. 기본 코드에는 별도 속도 모드 버튼이 없다.

[배선표](docs/wiring.md) · [단계별 부품표](docs/bom.md) · [구매 규격](../parts/purchasing/v2.md) · [부품 원리](../parts/PRINCIPLES.md)

## 실습 순서

[설치 안내](../course/setup/README.md)를 확인하고 표의 순서대로 각 스케치를 별도로 업로드한다.

| 스케치 | 실습 내용 |
|---|---|
| [00_print_mac](firmware/00_print_mac/00_print_mac.ino) | 각 ESP32의 STA MAC 주소 확인 |
| [01_joystick_read](firmware/01_joystick_read/01_joystick_read.ino) | 조이스틱 중심·방향과 정지 버튼 확인 |
| [02_espnow_sender_test](firmware/02_espnow_sender_test/02_espnow_sender_test.ino) | 차량 MAC을 입력하고 시험 패킷 송신 |
| [03_espnow_receiver_test](firmware/03_espnow_receiver_test/03_espnow_receiver_test.ino) | 시험 패킷 수신·출력 |
| [controller_joystick](firmware/controller_joystick/controller_joystick.ino) | ADC를 주행 패킷으로 변환·송신 |
| [vehicle_receiver](firmware/vehicle_receiver/vehicle_receiver.ino) | 무선 명령·전진 거리 조건·수신 시간 초과를 결합 |

## 확인할 결과

정지 버튼과 수신 중단 300ms 조건에서 정지하는지 측정한다. 전방 거리 조건은 전진보다 우선하며 후진·제자리 회전은 허용한다.

[요구사항](docs/requirements.md) · [시험 절차](docs/test-plan.md) · [장비 설정](../course/CONFIGURATION.md) · [실습 기록](../course/LAB_RECORD.md)

## 다음 단계

v3에서 같은 명령 패킷에 BMI270 기울기 입력을 연결한다.

[전체 학습 흐름](../course/README.md)

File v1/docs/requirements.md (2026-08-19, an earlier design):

# v1 요구사항 — 거리 감지와 안전 정지

- VL53L1X가 전방 거리를 50 ms 이상 주기로 측정한다.
- 50 cm 이내에서는 경고 상태를 출력한다.
- 20 cm 이내에서는 전진 명령을 차단하고 모터를 정지한다.
- 후진·좌·우 명령은 거리 안전 정지 상태에서도 허용한다.
- 거리 측정 실패 시 차량은 정지한다.

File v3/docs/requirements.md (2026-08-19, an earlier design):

# v3 요구사항 — BMI270 핸드 제스처 조종

- BMI270이 손 조종기의 Roll·Pitch 변화를 읽는다.
- 중립 자세를 기준으로 데드존을 적용한다.
- 전후 기울기는 전진·후진, 좌우 기울기는 조향 명령으로 바꾼다.
- 물리 정지 버튼과 v2 통신 끊김 정지는 항상 우선한다.
- v1 거리 안전 정지는 전진 명령보다 항상 우선한다.

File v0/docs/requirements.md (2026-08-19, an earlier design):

# RC Car v0 요구사항

## 사용자 시나리오

사용자는 ESP32가 제공하는 제어 명령으로 RC카를 전진, 후진, 좌회전, 우회전, 정지할 수 있다.

## 기능 요구사항

- 2개의 DC 기어드모터를 독립적으로 제어한다.
- 모터 방향을 반전할 수 있다.
- 정지 명령에서는 두 모터를 모두 정지한다.
- 전원을 켰을 때 모터가 임의로 움직이지 않는다.
- 향후 Wi-Fi 제어와 센서 기능을 추가할 수 있도록 핀 배치를 문서화한다.

## 비기능 요구사항

- ESP32 전원과 모터 전원은 분리된 DC-DC 출력으로 공급한다.
- 모든 모듈의 GND는 공통으로 연결한다.
- 모터 드라이버는 ESP32 GPIO에서 직접 모터 전류를 끌어오지 않는다.

## v0 범위 밖

- 자율주행, 카메라, LiDAR
- 전방 거리 감지와 장애물 안전 정지
- 조이스틱·버튼을 이용한 무선 조종
- BMI270 기반 핸드 제스처 조종

이 기능들은 기본 주행을 검증한 후 별도 Issue와 브랜치에서 추가한다.

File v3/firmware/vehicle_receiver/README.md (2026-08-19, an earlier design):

# 차량 수신기

v3의 차량 수신기는 v2의 `firmware/vehicle_receiver`를 그대로 사용한다. 통신 패킷 형식이 같으므로, BMI270은 조종기 쪽 입력만 바꾼다.

v1 거리 안전 정지 함수와 v2 통신 끊김 정지 기능은 제거하지 않는다.

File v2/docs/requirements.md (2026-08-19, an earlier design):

# v2 요구사항 — 조이스틱·버튼 무선 조종기

- 조종기와 차량은 ESP-NOW로 직접 통신한다.
- 조이스틱 Y축은 전진·후진, X축은 좌·우 조향에 사용한다.
- 정지 버튼은 즉시 모터를 정지한다.
- 차량이 300 ms 동안 명령을 못 받으면 자동 정지한다.
- v1의 전방 거리 안전 정지는 모든 전진 명령보다 우선한다.

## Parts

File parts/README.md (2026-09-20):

# 부품과 신호

| 부품 | 역할 | ESP32와 주고받는 것 | 단계 |
|---|---|---|---|
| ESP32 DevKit V1 | 입력을 읽고 명령·안전 조건을 계산 | GPIO, ADC, I²C, ESP-NOW, USB 시리얼 | 전체 |
| TB6612FNG | 별도 전원으로 모터를 구동 | 방향 디지털 신호와 PWM | 전체 |
| TT 기어드모터 | 2WD 기초 차량 구동 | 드라이버가 공급하는 모터 전력 | v0~v3 |
| VL53L1X | 전방 장애물까지 거리 측정 | I²C, mm 단위 거리값 | v1 이후 차량 |
| 조이스틱 | 전후·좌우 입력 | VRx/VRy 아날로그 전압→ADC 값 | v2 |
| 정지 버튼 | 조종기에서 정지 요청 | GPIO 4, INPUT_PULLUP, 눌림 LOW | v2·v3 |
| BMI270 | 3축 가속도·3축 각속도 측정 | I²C | v3 |
| 엔코더 N20 | 좌우 2구동륜과 회전 펄스 출력 | 모터 전력 입력, CHA 펄스 출력 | v4 |
| AA 4개·5V 벅-부스트 | 차량 모터 전원과 제어보드 전원 공급 | VM과 5V/VIN을 구분 | 차량 |
| 1셀 배터리·충전/보호·3.3V 레귤레이터 | 조종기 ESP32와 BMI270 전원 공급 | 셀 전압과 3.3V 레일을 구분 | v2·v3 조종기 |
| 브래킷·샤시·바퀴 | 부품 고정과 움직임 전달 | 장착홀·축·간섭 치수 | 제작 |

모터 전력, 제어 신호, 센서 통신, 무선 명령을 구분해서 배선도를 읽는다. 엔코더 CHA/CHB는 I²C가 아닌 디지털 펄스다.

- [전체 부품표](BOM.md)
- [작동 원리](PRINCIPLES.md)
- 단계별 구매 규격: [v0](purchasing/v0.md), [v1](purchasing/v1.md), [v2](purchasing/v2.md), [v3](purchasing/v3.md), [v4](purchasing/v4.md)
- 실제 핀은 각 버전의 docs/wiring.md를 따른다.

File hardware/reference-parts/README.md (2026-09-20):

# RC_CAR Fusion 360 참조 부품 묶음

이 폴더는 좌우 N20 엔코더 구동과 뒤쪽 수동 바퀴 2개를 사용하는 RC카 샤시를 설계할 때 부품을 Fusion 360 화면에 함께 띄워 놓기 위한 **배치·간섭 확인용 참조 모델**입니다.

실측 치수로 장착부를 만들려면 [실측 부품 기반 설계 안내](../fusion360/MEASURED_PARTS_WORKFLOW.md)를 먼저 확인하세요. 아래 STL은 실측 CAD가 아니며, 자동 생성기는 모든 치수·배치·축 관계가 연동되는 조립체가 아닙니다.

## 포함 파일

| 파일 | 용도 | 기준 외형 |
|---|---|---:|
| `N20_encoder_motor_reference.stl` | N20 엔코더 모터 외곽 | 본체 약 32.5 × 12 × 10 mm, 축 Ø3 × 9 mm |
| `wheel_70mm_reference.stl` | N20 호환 바퀴 외곽 | Ø70 × 22 mm, 보어 약 Ø3.2 mm |
| `N20_motor_bracket_reference.stl` | 교체형 모터 브래킷 외곽 | 약 40 × 18 × 27.5 mm |
| `ESP32_DevKit_V1_reference.stl` | ESP32 보드 외곽 | 약 55 × 28 × 12 mm |
| `TB6612FNG_breakout_reference.stl` | 모터 드라이버 보드 외곽 | 약 33 × 25 × 8 mm |
| `AA_4cell_holder_reference.stl` | 4칸 AA 배터리 홀더 외곽 | 약 60 × 32 × 31 mm |
| `buck_converter_reference.stl` | 5V 벅-부스트 컨버터 외곽 | 약 45 × 20 × 10 mm |
| `VL53L1X_reference.stl` | 전방 ToF 센서 외곽 | 약 21 × 17 × 6 mm |
| `M3_spacer_10mm_reference.stl` | 상부 데크 지지대 참조 | 외경 약 Ø6.4 × 10 mm |
| `RC_CAR_Reference_Assembly_Builder.py` | Fusion 360에서 참조 조립 배치를 자동 생성 | 샤시 + 주요 부품 외곽 |

## Fusion 360에서 가장 빠르게 쓰는 방법

### 방법 A: 전체 배치 자동 생성

1. Fusion 360에서 `Utilities → Scripts and Add-Ins`를 엽니다.
2. `+` 또는 `Add Existing Script`로 `RC_CAR_Reference_Assembly_Builder.py`를 등록합니다.
3. `Run`을 누릅니다.
4. `RC_CAR_REFERENCE_ASSEMBLY` 아래에 샤시와 부품 외곽이 생성됩니다.
5. 실제 모델링은 참조 부품을 기준으로 진행하고, 필요하지 않은 부품은 Browser의 전구를 끕니다.

### 방법 B: 필요한 STL만 직접 삽입

1. `Insert → Insert Mesh`를 선택합니다.
2. 원하는 `.stl` 파일을 선택합니다.
3. 단위를 `Millimeter`로 지정합니다.
4. `Move/Copy`와 `Align`으로 샤시에 배치합니다.

## 현재 RC_CAR 샤시에 들어갈 주요 부품

- N20 엔코더 기어드모터 × 2
- N20 호환 구동 바퀴 × 2
- 자유회전 수동 바퀴 참조 외곽 × 2
- N20 교체형 모터 브래킷 × 2
- ESP32 DevKit V1 × 1
- TB6612FNG 모터 드라이버 × 1
- 4칸 AA 배터리 홀더 × 1
- 5V 2A 이상 벅-부스트 컨버터 × 1 (차량 ESP32용)
- VL53L1X ToF 거리 센서 × 1
- M3 스페이서·나사·인서트
- 전원 스위치, 커패시터, 배선과 커넥터

## 반드시 확인할 점

이 모델들은 특정 판매자의 제품 CAD를 복제한 것이 아니라, 현재 저장소의 치수 기준으로 만든 **참조 외곽 모델**입니다. 실제 출력 전에는 다음을 캘리퍼스로 확인해야 합니다.

- N20 모터의 엔코더 PCB까지 포함한 전체 길이
- 브래킷 고정홀 간격과 축 중심 높이
- 실제 바퀴 보어와 D축 형상
- ESP32 USB 포트 방향
- TB6612FNG 보드 홀 위치
- 4×AA 홀더의 외곽과 스위치 위치

FDM 출력에서는 체결 여유를 우선 `0.4 mm`부터 시험하고, 실제 프린터와 재료에 맞춰 조정하세요. 최종 제작용 치수로 바로 사용하지 마세요.

기술 기준: `course/README.md`, `parts/BOM.md`, `hardware/fusion360/DIMENSION_SOURCES.md`.

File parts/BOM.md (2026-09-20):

# 전체 부품표

수량은 차량 1대와 조종기 1개 기준이다. v4의 '총 필요량'을 이전 버전 수량에 다시 더하지 않는다.

| 부품 | v0~v3 구성 | v4 최종 구성 | 설명 |
|---|---:|---:|---|
| ESP32 DevKit V1 | 차량 1개 + v2부터 조종기 1개 | 총 2개 | 차량·조종기 분리 |
| TT 모터·바퀴 | 각 2개 | 사용하지 않음 | 기초 2WD 실습 |
| 엔코더 N20 모터 | 없음 | 2개 | 좌우 구동축, 문서 기준 6V 약 100RPM. 실물 사양 확인 |
| 수동 바퀴·축/브래킷 | 없음 | 2개 | 뒤쪽 자유회전 지지륜, 실제 높이·간섭 확인 |
| TB6612FNG | 1개 | 총 1개 | 좌우 모터에 두 채널 사용 |
| VL53L1X | v1부터 1개 | 1개 재사용 | 차량 전방 |
| 조이스틱 | v2 1개 | v2 조종기 선택 시 1개 | v3에서는 BMI270으로 입력 교체 |
| BMI270 | v3 1개 | v3 조종기 선택 시 1개 | 3.3V 호환 I²C 모듈 |
| 정지 버튼 | v2부터 1개 | 1개 재사용 | 속도 버튼은 기본 코드에 없음 |
| AA 알카라인 4개·홀더·스위치 | 1세트 | 1세트 | 차량 전원 |
| 5V 2A 이상 벅-부스트 | 1개 | 1개 | 선택한 부품의 입력 범위·출력 용량 확인 |
| 470µF 이상 전해 커패시터 | 1개 | 총 1개 | 드라이버 VM-GND 가까이에, 극성·정격 확인 |
| N20 브래킷 | 없음 | 2개 | 모터·엔코더 PCB와 간섭 확인 |
| 10kΩ 저항 | 필요에 따라 | 최대 2개 | 엔코더가 오픈 컬렉터일 때 좌우 CHA 풀업 |
| 1셀 배터리·보호/충전 모듈·3.3V 레귤레이터 | 조종기용 | 조종기용 | 일반 Li-ion 셀을 3V3에 직접 연결하지 않음 |
| 배선·커넥터·M3 나사·스페이서 | 필요량 | 필요량 | 실제 장착홀과 전류에 맞춤 |

ESP32 핀에 5V 엔코더 출력을 직접 연결하지 않는다. 실제 엔코더 출력 방식·로직 전압, 모터 정지전류, 드라이버와 전원 용량을 확인한다. 부품명이나 외형이 같아도 판매 옵션에 따라 규격이 다를 수 있다.

제품 선정과 구매 URL 기록은 [단계별 구매 규격](README.md)을 사용한다.

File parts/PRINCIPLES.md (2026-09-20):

# 최종 차량과 조종기의 부품 원리

> 범위: 현재 저장소의 최종 목표인 **v4 2구동륜 엔코더 N20 RC카 + v3 BMI270 핸드 제스처 조종기**만 다룬다.
> TT 모터, 조이스틱, 초음파센서, 플렉스센서 등 현재 최종 구성에 사용하지 않는 부품은 포함하지 않는다.

---

## 전체 시스템과 전원

### 최종 시스템 구조

```text
손 조종기 ESP32 + BMI270 + 정지 버튼
                 │
                 │ ESP-NOW
                 ▼
차량 ESP32 ── VL53L1X 전방 거리센서
     │
     └── TB6612FNG ── 좌우 N20 구동 모터
                         │
                    좌우 엔코더 펄스
                         ▼
                  차량 ESP32의 좌우 RPM·PID 보정

뒤쪽에는 모터와 엔코더가 없는 자유회전 수동 바퀴 2개를 둔다.
```

### 사용하는 부품과 역할

| 부품 | 수량 | 이 프로젝트에서의 역할 |
|---|---:|---|
| ESP32 DevKit V1 | 2 | 손 조종기 송신기 1개, 차량 제어기 1개 |
| BMI270 브레이크아웃 | 1 | 손의 기울기와 회전 측정 |
| VL53L1X ToF 센서 | 1 | 차량 전방 거리 측정과 안전 정지 |
| TB6612FNG | 1 | 좌우 N20 모터를 두 채널로 PWM 제어 |
| 엔코더 포함 N20 메탈 기어드모터 | 2 | 좌우 감속·구동·회전 펄스 출력 |
| 3mm D축 호환 구동 바퀴 | 2 | N20 출력축의 회전을 지면 이동으로 변환 |
| 자유회전 수동 바퀴 | 2 | 뒤쪽 지지와 접지 |
| N20 금속 브래킷 | 2 | 좌우 모터를 3D 프린팅 샤시에 고정 |
| AA 알카라인 배터리 4개와 홀더 | 1세트 | 차량 모터와 전원 변환기의 입력 |
| 5V 2A 이상 벅-부스트 컨버터 | 1 | 차량 ESP32에 안정적인 5V 공급 |
| 470uF 이상 전해 커패시터 | 1 | TB6612FNG의 모터 전원 노이즈 완화 |
| 10kΩ 저항 | 최대 2 | 오픈 컬렉터 엔코더 A 신호 풀업 |
| 정지 버튼·배선·커넥터·M3 체결부 | 필요량 | 비상정지, 연결, 조립 |

### 전원의 흐름

```text
AA 4개 약 6V
   ├── 스위치 ── TB6612FNG VM ── 좌우 N20 모터 전원
   └── 5V 벅-부스트 ── 차량 ESP32 5V/VIN

차량 ESP32 3V3 ── TB6612FNG VCC
               ├─ VL53L1X 전원
               └─ 엔코더 로직 전원

모든 GND ─────── 차량 장치 내부에서 공통 연결

조종기: 1셀 배터리 → 보호·충전 → 3.3V 레귤레이터 → ESP32·BMI270
```

전압은 부품에 맞춰야 하고, 전류 용량은 충분해야 한다. 모터가 출발할 때 큰 전류를 요구하면서 전원 전압이 흔들릴 수 있으므로 470uF 커패시터를 각 드라이버의 `VM-GND` 근처에 배치한다. 모터 전원은 ESP32 GPIO에서 가져오지 않는다.

### 강의 핵심 문장

> ESP32는 명령을 계산하고, TB6612FNG는 모터 전류를 스위칭하며, N20 모터는 실제 힘을 만든다. 센서와 모터의 전원 역할을 분리해야 안정적으로 동작한다.

---

## TB6612FNG·N20 모터·바퀴·엔코더

### TB6612FNG의 원리

TB6612FNG는 ESP32의 작은 GPIO 신호로 모터를 직접 구동하는 부품이 아니다. ESP32가 `IN1`, `IN2`, `PWM` 신호를 보내면 TB6612FNG 내부의 H-브리지 회로가 모터 전원 `VM`을 빠르게 스위칭한다.

| 입력 상태 | 모터 동작 |
|---|---|
| IN1=HIGH, IN2=LOW | 정방향 |
| IN1=LOW, IN2=HIGH | 역방향 |
| IN1=LOW, IN2=LOW | 정지 또는 coast |
| PWM의 듀티비 증가 | 평균 모터 전압과 속도 증가 |
| STBY=LOW | 드라이버 대기·출력 비활성 |
| STBY=HIGH | 드라이버 활성 |

현재 v4에서는 TB6612FNG 한 개의 두 채널을 좌우 모터 하나씩 사용한다. 두 모터를 한 채널에 병렬로 연결하지 않는다. 모터마다 기동전류와 마찰이 다르기 때문에 독립적으로 PWM과 PID를 조정해야 한다. 수동 바퀴는 제어 채널과 엔코더를 갖지 않는다.

### N20 모터의 구조

```text
DC 모터의 빠른 회전
        ↓
금속 감속기: 속도 감소, 토크 증가
        ↓
3mm D축 출력축
        ↓
바퀴 회전과 차량 이동
```

N20의 모터 내부는 빠르게 회전하지만, 금속 기어가 회전수를 낮추고 출력 토크를 높인다. 따라서 모터의 RPM만 보고 바퀴 속도를 판단하면 안 된다. 감속비, 바퀴 지름, 실제 부하를 함께 봐야 한다.

### 홀 엔코더의 원리

모터 뒤쪽의 자석이 회전하고, 홀 센서가 자기장 변화를 감지한다.

```text
자석 회전 → 홀 센서 감지 → CHA/CHB 디지털 펄스 → ESP32 인터럽트
```

- 펄스의 개수: 얼마나 회전했는지
- 펄스가 발생한 시간: 얼마나 빠르게 회전하는지
- CHA와 CHB의 위상 차이: 회전 방향 판단

현재 v4 기본 코드는 `CHA`만 읽어 RPM을 측정하고, 회전 방향은 TB6612FNG에 보낸 모터 명령을 기준으로 판단한다. `CHB`는 기본 실습에서는 연결하지 않는다.

### RPM 계산

```text
RPM = 일정 시간 동안 센 펄스 수
      × 60
      ÷ (측정 시간(초) × 1회전당 펄스 수)
```

`PULSES_PER_WHEEL_REV`는 엔코더 제품의 감속비와 출력축 기준에 따라 달라지므로, 바퀴를 정확히 한 바퀴 돌려 실제 펄스 수를 측정해야 한다.

### PID 속도 보정

```text
목표 RPM
   ↓
오차 = 목표 RPM - 실제 RPM
   ↓
PID 계산
   ↓
TB6612FNG PWM 보정
   ↓
N20 모터 속도 변화
   ↓
엔코더가 다시 측정
```

### 강의 핵심 문장

> 모터의 PWM은 명령값이고, 엔코더 RPM은 결과값이다. PID는 두 값의 차이를 줄이는 피드백 제어다.

---

## VL53L1X 거리센서와 BMI270 IMU

### VL53L1X의 역할과 원리

VL53L1X는 차량 앞의 장애물까지 거리를 측정하는 ToF(Time of Flight) 센서다.

```text
적외선 펄스 발사 → 물체 반사 → 반사광 수신
                         ↓
                 빛의 왕복 시간 계산
                         ↓
                       거리(mm)
```

거리값을 반복 갱신하며, 전진 명령에서 `STOP_MM = 200` 이하이면 모터를 정지시킨다. 유효한 측정값이 없거나 250ms 넘게 갱신되지 않아도 전진을 차단한다. 후진·제자리 회전은 허용한다.

### VL53L1X 핀맵

| VL53L1X | 차량 ESP32 | 역할 |
|---|---:|---|
| VIN | 3.3V | 센서 전원 |
| GND | GND | 공통 접지 |
| SDA | GPIO21 | I²C 데이터 |
| SCL | GPIO22 | I²C 클록 |
| XSHUT | 미연결 | 센서 1개에서는 선택사항 |

센서는 차체 전면을 향하게 고정하고, 모터 전원선과 센서 배선을 가능한 한 떨어뜨린다.

### BMI270의 역할과 원리

BMI270은 손 조종기에 장착하는 6축 IMU다.

- 가속도계 3축: 중력과 직선 가속도 측정
- 자이로스코프 3축: X·Y·Z축 회전 속도 측정
- 가속도계의 중력 성분으로 Roll·Pitch 계산
- 계산된 기울기를 ESP-NOW 명령으로 변환

```text
손의 기울기
    ↓
BMI270 가속도 데이터
    ↓
Roll·Pitch 계산
    ↓
데드존 적용
    ↓
throttle·steering 명령 생성
    ↓
ESP-NOW로 차량 ESP32에 전송
```

### BMI270 핀맵

| BMI270 | 조종기 ESP32 | 역할 |
|---|---:|---|
| VIN | 3.3V | 센서 전원 |
| GND | GND | 공통 접지 |
| SDA | GPIO21 | I²C 데이터 |
| SCL | GPIO22 | I²C 클록 |
| INT1 | GPIO27 | 동작 인터럽트, 선택사항 |

현재 조종기 코드는 전원을 켤 때 100개의 가속도 샘플을 읽어 손의 중립 자세를 계산한다. 이후 `±8도`는 데드존으로 무시하고, 최대 약 `35도`까지 기울기를 PWM 명령 범위로 변환한다.

### 강의 핵심 문장

> VL53L1X는 차량 주변의 위험을 감지하고, BMI270은 운전자의 손동작을 감지한다. 하나는 차량 안전용이고, 다른 하나는 조종 입력용이다.

---

## 전체 핀맵과 실습 순서

### 차량 ESP32 최종 핀맵

| 위치 | TB6612FNG 채널 | IN1 | IN2 | PWM | 엔코더 CHA |
|---|---|---:|---:|---:|---:|
| 좌측 구동 FL | A | GPIO18 | GPIO19 | GPIO13 | GPIO34 |
| 우측 구동 FR | B | GPIO23 | GPIO25 | GPIO14 | GPIO35 |
| 뒤 수동 RL/RR | 연결 없음 | - | - | - | - |

추가 연결:

```text
TB6612FNG STBY → ESP32 3.3V
TB6612FNG VCC  → ESP32 3.3V
VL53L1X SDA       → GPIO21
VL53L1X SCL       → GPIO22
```

GPIO 34, 35, 36, 39는 입력 전용이며 내부 풀업이 없다. 엔코더가 오픈 컬렉터 방식이면 각 `CHA` 신호와 3.3V 사이에 10kΩ 저항을 연결한다. 엔코더 출력이 5V라면 ESP32에 직접 연결하지 말고 3.3V 호환 여부를 확인한다.

### 조종기 ESP32 최종 핀맵

| 부품 | ESP32 |
|---|---:|
| BMI270 SDA | GPIO21 |
| BMI270 SCL | GPIO22 |
| BMI270 INT1 | GPIO27, 선택 |
| 정지 버튼 | GPIO4 |
| 버튼 반대쪽 | GND |

### 실습 진행 순서

1. `v3/firmware/00_bmi270_read`로 가속도·자이로 값을 확인한다.
2. `v1/firmware/01_distance_read`로 VL53L1X 거리값을 확인한다.
3. `v4/firmware/00_encoder_read`로 좌우 구동 모터의 엔코더 펄스를 확인한다.
4. `v0/firmware/01_motor_test`로 TB6612FNG와 모터 방향을 확인한다.
5. `v4/firmware/01_speed_pid_tune`으로 목표 RPM과 실제 RPM을 비교한다.
6. `v3/firmware/controller_bmi270`으로 손 기울기 명령을 ESP-NOW로 전송한다.
7. `v4/firmware/vehicle_encoder_receiver`에서 거리 정지·ESP-NOW·PID를 통합한다.

### Python 실습의 범위

현재 센서는 ESP32의 I²C GPIO에 직접 연결되어 있고, 임베디드 펌웨어는 Arduino C++로 작성되어 있다. 따라서 PC의 Python이 ESP32 GPIO를 직접 읽는 방식이 아니라, **ESP32가 시리얼로 출력한 센서값을 Python이 읽고 계산·분석**하는 방식으로 구성한다.

Python 실습 파일은 다음 로그를 분석한다.

- BMI270: 가속도·자이로 → Roll·Pitch → 제스처 명령
- VL53L1X: 거리(mm) → 경고·정지 판정
- N20 엔코더: 펄스·RPM → 좌우 구동축 속도 편차 확인
- TB6612FNG 모터 실습: 시리얼 명령으로 안전 정지 테스트

---

## 실습 안전 체크

- 배선 변경 전 AA 배터리 전원을 끈다.
- ESP32 GPIO에는 3.3V를 넘는 신호를 입력하지 않는다.
- TB6612FNG의 `VM`은 모터 전원, `VCC`는 로직 전원이다.
- 모터를 공중에 띄우고 방향·엔코더를 먼저 확인한다.
- 전진 명령에서 VL53L1X가 `200mm` 이하 장애물을 감지하면 정지해야 한다.
- ESP-NOW 통신이 300ms 이상 끊기면 차량을 정지시킨다.

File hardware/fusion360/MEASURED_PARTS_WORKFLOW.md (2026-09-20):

# 실측 부품을 기준으로 Fusion 360 차체 설계하기

대상은 **v4 N20 엔코더 2구동륜 차량의 모터 장착·부품 배치 실습**이다. 뒤쪽에는 별도 모터가 없는 수동 바퀴 2개를 사용한다. v0~v3 TT 2륜 차량과 v2·v3 조종기에서 달라지는 부품도 아래에 구분했다.

구매 부품을 실제 크기의 참조 컴포넌트로 배치하고, 그 주변에 모터 마운트·배터리 트레이·전자부품 데크·차체를 설계한다. **부품의 실측치, 끼워 맞춤 여유, 차체 설계값은 서로 다른 값으로 관리한다.**

현재 구매 목록에는 정확한 제품 URL이 기록되지 않았다. 기존 참조 STL과 생성기의 기본 치수는 구매품의 실측값이 아니다. 이 안내는 실제 Fusion 조립이나 시험 출력이 완료되었다는 뜻이 아니다.

## 1. Fusion에 배치할 부품과 현재 파일

수량은 v4 차량 1대 기준이다. 동일 부품은 모델 하나를 확인한 뒤 필요한 수만큼 배치하되, 실제 구매품의 편차도 확인한다.

| 부품 | 수량 | 현재 사용할 수 있는 파일 | 실측으로 확인할 핵심 |
|---|---:|---|---|
| N20 엔코더 기어드모터 | 2 | [N20_encoder_motor_reference.stl](../reference-parts/N20_encoder_motor_reference.stl) | 좌우 기어박스·본체·엔코더의 외곽, 출력축 중심·지름·D컷·돌출 길이, 케이블 출구 |
| N20 호환 구동 바퀴 | 2 | [wheel_70mm_reference.stl](../reference-parts/wheel_70mm_reference.stl) | 좌우 타이어 지름·폭, 허브 돌출, 축 구멍 형상·깊이, 모터에 끼운 뒤 안쪽 면 위치 |
| 수동 바퀴 | 2 | 구매품 실측 후 별도 참조 | 뒤쪽 접지 높이·축/캐스터 간섭·자유회전 상태 |
| N20 브래킷 | 2 | [N20_motor_bracket_reference.stl](../reference-parts/N20_motor_bracket_reference.stl) | 바닥 체결홀, 축 중심 높이, 엔코더 간섭. 금속 구매품과 출력 마운트는 구분 |
| ESP32 DevKit V1 | 1 | [ESP32_DevKit_V1_reference.stl](../reference-parts/ESP32_DevKit_V1_reference.stl) | 보드 외곽, 핀헤더 포함 위·아래 높이, 실제 장착홀, USB 포트·플러그 공간 |
| TB6612FNG 모듈 | 1 | [TB6612FNG_breakout_reference.stl](../reference-parts/TB6612FNG_breakout_reference.stl) | 모듈 PCB 외곽·홀·핀헤더·연결 케이블 높이 |
| AA 4개 홀더 | 1 | [AA_4cell_holder_reference.stl](../reference-parts/AA_4cell_holder_reference.stl) | 배터리·뚜껑·스위치 포함 외곽, 체결부, 배터리 교체 방향 |
| 5V 벅-부스트 모듈 | 1 | [buck_converter_reference.stl](../reference-parts/buck_converter_reference.stl) | 실제 보드 외곽·홀, 가장 높은 부품, 단자·조정 나사 접근 공간 |
| VL53L1X 모듈 | 1 | [VL53L1X_reference.stl](../reference-parts/VL53L1X_reference.stl) | PCB 외곽·홀, 광학창 중심·방향, 헤더·케이블 공간 |
| 나사·너트·스페이서·인서트 | 설계에 따라 | [M3_spacer_10mm_reference.stl](../reference-parts/M3_spacer_10mm_reference.stl)는 스페이서 예시만 제공 | 실제 길이·외경·나사머리·너트 폭, 공구 공간, 인서트 제조사 권장 홀 |
| 전원 스위치·커패시터·커넥터·배선 | 스위치는 구성에 따라, 커패시터 1개, 나머지 필요량 | 전용 모델 없음 | 스위치 패널 구멍·걸쇠, 커패시터 지름·높이, 플러그 삽입·분리와 선의 굽힘 공간 |

위 STL은 모두 **배치 참고용**이다. `wheel_70mm`라는 이름이 실제 바퀴가 70 mm라는 뜻은 아니며, `buck_converter` 파일도 특정 벅-부스트 제품의 CAD가 아니다. 나사·보드·센서는 명칭이 같아도 판매 옵션에 따라 크기와 홀 위치가 달라진다. 특히 TB6612FNG·VL53L1X·BMI270은 **칩 단품 CAD가 아니라 구매한 모듈 전체의 CAD**가 필요하다.

기존 [N20withEncoder_mount.stl](../stl/N20withEncoder_mount.stl)은 출력 마운트 후보이며 모터 참조 모델과 다르다. 실측 적합성을 확인하기 전에는 그대로 양산하지 않는다.

### 다른 버전과 조종기

| 대상 | 추가하거나 교체할 참조 부품 | 현재 자료 |
|---|---|---|
| v0~v3 TT 2륜 차량 | TT 모터 2개, 호환 바퀴 2개, 볼 캐스터 1개. 드라이버는 1개 | 정확한 부품별 CAD 없음. v4 N20 모델을 크기만 늘려 사용하지 않는다 |
| v2 조이스틱 조종기 | 차량과 별도의 ESP32 1개, 조이스틱 1개, 정지 버튼 1개, USB 플러그. 보조배터리를 내장할 경우 그 외곽도 포함 | [케이스 상판](../stl/controller-top.STL)·[하판](../stl/controller-bottom.STL)은 케이스 후보이며 내부 부품의 실측 CAD가 아니다 |
| v3 제스처 조종기 | ESP32·정지 버튼·USB 공간과 BMI270 1개. 기본 입력은 조이스틱에서 BMI270으로 교체 | BMI270 참조 CAD 없음. 보드 축 방향도 표시하여 코드의 좌표계와 맞춘다 |

## 2. 어떤 파일을 확보하고 저장할까

| 목적 | 권장 파일 | 쓰는 방법과 한계 |
|---|---|---|
| 구매 부품의 3D 형상 확보 | **STEP / STP** | 정확한 제조사·모델·보드 리비전의 파일을 우선 확보한다. 면·축·홀을 기준으로 배치하기 좋지만 실물과 대조해야 한다. 원래 CAD의 스케치·설계 이력을 담는 형식은 아니다 |
| 실측해서 직접 만든 부품·마운트 수정 | **Fusion 원본 / F3D** | 스케치와 파라미터를 연결한 상태로 저장한다. 외부 참조가 있는 조립체의 로컬 내보내기는 F3Z 묶음이 될 수 있다 |
| 외곽 배치 참고, 기존 출력물 참조 | **STL / 3MF** | 메시로 삽입한다. STEP이나 파라메트릭 원본과 같지 않다. STL을 STEP으로 변환해도 누락된 실측 정보나 설계 이력이 생기지 않는다 |
| 2D 외곽·홀 패턴 | DXF | 실제 축척과 치수 확인 후 스케치로 삽입한다. 높이는 별도로 입력한다 |
| 치수 도면·사진 기록 | PDF, PNG, JPG | PDF 도면을 읽고 치수를 입력한다. 이미지를 Canvas로 쓰는 경우 알려진 길이로 Calibrate하되 사진 원근과 왜곡을 고려한다 |
| 완성한 출력 부품을 슬라이서로 전달 | **3MF 또는 STL** | 차체·마운트 등 출력 대상만 내보낸다. 모터·보드·배터리 참조 모델은 제외한다 |

Fusion 원본과 외부 참조의 저장 형식은 [Autodesk 로컬 아카이브 안내](https://www.autodesk.com/support/technical/article/caas/sfdcarticles/sfdcarticles/How-to-make-a-local-archive-back-up-file-in-Fusion-360.html)를 참고한다.

CAD는 구매한 제품 페이지의 CAD/Download/Mechanical Drawing에서 먼저 찾는다. 없으면 판매자에게 정확한 옵션의 STEP과 치수 도면을 요청하거나 직접 측정해 단순 모델을 만든다. 외형이 비슷한 다른 제품의 모델은 임시 배치용으로만 분류한다.

기성품 모델에는 작은 저항·문자·기어 내부를 모두 재현할 필요가 없다. **외곽, 장착면, 체결홀, 축, 돌출부, 커넥터 위치**를 정확하게 만들면 장착 설계에 사용할 수 있다.

Fusion에서는 원본을 프로젝트에 저장하고, 로컬 파일 이름은 `정확한모델명_리비전.step`, `정확한모델명_measured.f3d`처럼 출처와 상태를 구분한다. 측정 전에는 `measured`로 이름 붙이지 않는다. 제작 중간 파일·측정 사진·시험 출력 기록은 로컬 `_local`에 보관한다. 수업에 사용할 최종 설계 파일은 `hardware`에 두고 README에 연결한다. 외부 CAD의 공개 재배포 가능 여부는 해당 출처의 조건을 확인한다.

## 3. 실측 기록 방법

캘리퍼스의 영점을 확인하고 단위를 mm로 통일한다. 보드의 맨바닥 크기만 재지 말고 **핀헤더·커넥터가 장착된 실제 사용 상태**도 측정한다. 아직 확인하지 못한 값은 빈칸 또는 ‘미측정’으로 남긴다.

부품마다 아래 양식을 복사해 기록한다. 기준면·원점을 먼저 정해야 홀 좌표를 나중에 다시 사용할 수 있다.

| 기록 항목 | 입력 |
|---|---|
| 부품 이름 / 판매처 / 모델 / 옵션 / 리비전 | 미기록 |
| 실측일 / 측정 도구 / 표본 번호 | 미기록 |
| 치수 출처 구분: 실측 / 해당 모델 도면 / 임시값 | 미기록 |
| 장착 기준면 / 원점 / X·Y·Z 방향 | 미기록 |
| 본체 길이 L / 폭 W / 높이 H (mm) | 미측정 |
| 장착면 아래 돌출 높이 / 위쪽 최대 높이 (mm) | 미측정 |
| 홀별 지름 및 중심 좌표 X·Y (mm) | 미측정 |
| 축 중심 좌표·높이 / 축 지름 / D컷 / 돌출 길이 | 해당 시 미측정 |
| 케이블·커넥터 출구 위치 / 플러그 장착 후 외곽 | 미측정 |
| 조립·분해·배터리 교체·공구에 필요한 공간 | 미확인 |
| 사용 CAD 파일 / 실물과 다른 부분 | 미기록 |

모터는 축 방향을 길이로 하고 기어박스 앞면·출력축 중심을 기준으로 삼는다. PCB는 장착면과 한 모서리를 기준으로 홀 중심을 기록한다. 바퀴는 축 중심·허브 장착면을 기준으로 한다. CAD를 가져온 뒤 모델 원점이 이 기준과 다르면 기준 축·평면을 만들어 배치한다.

같은 지름의 홀 두 개는 ‘바깥쪽 끝 간 거리 − 홀 지름’ 또는 ‘안쪽 끝 간 거리 + 홀 지름’으로 중심 간격을 확인할 수 있다. 장착홀을 단순히 보드 가장자리에서 눈대중으로 배치하지 않는다.

## 4. Fusion에서 불러오기

### STEP을 확보한 경우

1. Data Panel → Upload에서 STEP/STP 파일을 올린다.
2. 변환된 부품을 열고 Inspect → Measure로 알려진 길이와 비교한다. 실측치와 차이가 나면 제품 옵션·모델 버전·누락된 커넥터 등을 확인한다.
3. 부품을 저장한다. 차체와 부품을 함께 작업할 새 디자인은 **Hybrid Design**으로 만든다. 구버전에서는 이에 해당하는 일반 Design을 사용한다.
4. Data Panel의 부품을 우클릭 → **Insert into Current Design**으로 삽입한다. 이렇게 넣은 부품은 원본과 연결된 외부 컴포넌트가 된다.

절차 출처: [Autodesk 파일 가져오기](https://help.autodesk.com/view/fusion360/ENU/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), [다른 디자인 삽입](https://help.autodesk.com/view/fusion360/ENU/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).

### 지금 있는 STL을 쓰는 경우

1. 부품별 컴포넌트를 만들고 활성화한다.
2. **Insert Mesh**를 실행한다. Mesh → Create 또는 Insert 메뉴에서 찾을 수 있다.
3. 위 표의 STL을 선택하고 **Millimeter**로 삽입한다. STL 자체에는 단위 정보가 없으므로 크기를 반드시 확인한다.
4. 부품별로 배치한다. 크기가 실물과 다르면 중요한 외곽·축·홀을 실측으로 다시 모델링한다. 전체 메시를 비례 확대하면 홀 간격과 축 지름까지 함께 바뀌므로 실측 보정으로 간주하지 않는다.

절차 출처: [Autodesk Insert Mesh](https://help.autodesk.com/cloudhelp/ENU/Fusion-Mesh/files/MESH-INSERT-MESH.htm), [STL 단위 안내](https://help.autodesk.com/view/fusion360/ENU/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).

## 5. 실측 모델과 출력 여유를 연결하기

Modify → Change Parameters에서 아래와 같이 이름을 정한다. 아래 목록은 **새로 구성할 설계의 예시**이며 기존 생성기의 파라미터 이름과 자동으로 연결되지 않는다.

| 파라미터 예시 | 입력할 내용 |
|---|---|
| `motor_w`, `motor_h`, `motor_total_l` | 실측한 모터 외곽. 엔코더 포함 여부를 설명에 기록 |
| `shaft_d`, `shaft_l`, `shaft_center_z` | 실측한 출력축과 장착 기준면 사이 관계 |
| `bracket_hole_pitch_x`, `bracket_hole_pitch_y` | 구매 브래킷의 실제 홀 중심 간격 |
| `wheel_d`, `wheel_w`, `hub_offset` | 실측한 바퀴와 장착면 관계 |
| `battery_l`, `battery_w`, `battery_h` | 실제 사용 상태의 홀더 외곽 |
| `fit_gap_side` | 한쪽 면에 주는 끼움 여유. 실측치와 별도 관리 |
| `wire_space`, `usb_service_space` | 실제 커넥터와 케이블의 조작 공간 |
| `wall_t`, `wheelbase`, `track_width` | 출력 벽 두께, 앞뒤 축 간 거리, 좌우 바퀴 중심 간 거리라는 설계값 |

실측 부품 컴포넌트는 실제 크기로 유지하고, **마운트의 안쪽 크기에만 여유를 더한다.** 예를 들어 다음처럼 스케치 치수에 식을 입력한다.

```text
모터 받침 안쪽 폭 = motor_w + 2 * fit_gap_side
배터리 트레이 안쪽 길이 = battery_l + 2 * fit_gap_side
배터리 트레이 안쪽 폭 = battery_w + 2 * fit_gap_side
```

파라미터를 목록에 등록하는 것만으로 형상이 바뀌지 않는다. 스케치 치수·Extrude 거리·배치 기준이 해당 파라미터나 식을 실제로 참조해야 한다. [Autodesk 파라미터 작성 안내](https://help.autodesk.com/cloudhelp/ENU/Fusion-Model/files/SLD-MODIFY-CHANGE-PARAMETERS.htm).

한쪽 여유 0.20 / 0.30 / 0.40 mm를 비교하는 작은 끼움 시편을 첫 실험으로 만들 수 있다. 이는 **제안하는 시험값**이며 프린터의 보장 공차나 부품 실측치가 아니다. 통과홀·모터 고정·인서트 홀에는 각각 맞는 시험을 한다. 특히 인서트 홀은 실제 인서트 제조사 권장값에서 시작한다. 기존 생성기의 `fit_clearance = 0.4 mm`를 새 설계의 ‘한쪽 여유’와 동일하다고 가정하지 않는다.

## 6. 부품을 기준으로 차체를 만드는 순서

1. **좌표와 배치를 정한다.** X=차량 좌우, Y=앞뒤, Z=위로 통일한다. 바닥 평면과 바퀴 축선을 먼저 정하고 휠베이스·윤거·필요 지상고를 설계값으로 둔다. 기존 300×400 mm 또는 320×420 mm를 고정 조건으로 가져오지 않는다.
2. **모터·바퀴·브래킷 한 세트부터 맞춘다.** 축과 허브를 동심으로 맞추고 실제 삽입 깊이를 반영한다. 타이어가 브래킷이나 차체에 닿지 않는지, 모터 뒤 엔코더와 케이블이 들어가는지 확인한다. 구입한 금속 브래킷을 사용하면 실제 홀 패턴에 맞는 차체 어댑터를 설계하고, 출력 브래킷을 사용하면 실제 모터를 기준으로 클램프를 설계한다.
3. **확인한 세트를 네 위치에 배치한다.** Move/Copy·Align으로 초기 위치를 잡고 고정부는 Rigid Joint 등으로 관계를 정한다. 필요하면 바퀴 회전 관계를 별도로 만든다. 구매품 복제는 실제 부품의 방향 전환으로 처리하고, 비대칭 부품을 Mirror하여 실재하지 않는 반대손 부품을 만들지 않는다.
4. **배터리를 낮고 중앙 가까이에 배치한다.** 홀더를 차체에서 빼지 않고 배터리를 바꿀지, 홀더째 뺄지 정한 뒤 트레이·스트랩 슬롯·덮개 공간을 설계한다.
5. **전자부품과 서비스 공간을 놓는다.** ESP32의 USB 연결, TB6612FNG 1개의 배선, 벅-부스트의 단자, 스위치 조작, 커패시터 높이를 포함한다. 실제 장착홀이 없는 보드는 임의의 M3 홀을 뚫는 대신 가장자리 지지·클립·별도 캐리어를 설계한다. 안테나 앞 공간도 확보한다.
6. **전방 센서 위치를 확정한다.** VL53L1X의 광학창을 전방으로 향하게 하고 범퍼·차체가 시야를 가리지 않게 한다. 제품의 시야각 자료와 실제 감지 시험으로 위치를 확인한다.
7. **그 사이를 차체로 연결한다.** `CHASSIS`, `MOTOR_MOUNT`, `BATTERY_TRAY`, `ELECTRONICS_DECK`, `SENSOR_BRACKET`처럼 출력물을 별도 컴포넌트로 만든다. 장착면·홀 → 기본 판 → 보강 리브 → 필렛 순서로 설계한다. 외곽 전체보다 체결 기준을 먼저 잡는다.
8. **조립·분해와 간섭을 확인한다.** 솔리드 참조 모델과 출력물에 Inspect → Interference를 사용하고 단면·치수 측정도 확인한다. STL 외곽만 보았다고 전체 간섭 검사가 완료된 것으로 기록하지 않는다. 케이블 굽힘, USB 탈착, 드라이버 공구, 배터리 교체 공간은 별도 단순 솔리드로 표시하면 검토하기 좋다. [Autodesk 간섭 검사](https://help.autodesk.com/view/fusion360/ENU/?contextId=DESIGN-INSPECT-INTERFERENCE-CMD).
9. **브래킷 한 개와 홀 시편부터 출력한다.** 모터 고정, 엔코더 공간, 바퀴 회전, 나사 체결을 실물로 확인하고 치수를 보정한다. 이후 전체 차체를 출력한다. 프린터의 실제 출력 가능 영역과 브림 공간을 확인하여 크기·분할·접합 위치를 정한다.
10. **원본과 출력 파일을 구분해 저장한다.** 수정 가능한 Fusion 원본을 저장하고 출력 대상 컴포넌트만 우클릭 → Save As Mesh → 3MF 또는 STL로 내보낸다. STL은 mm로 저장하고 슬라이서에서 알려진 길이를 한 번 더 확인한다. [Autodesk 메시 내보내기](https://help.autodesk.com/cloudhelp/ENU/Fusion-Mesh/files/MESH-SAVE-AS-MESH.htm).

## 7. 기존 생성기는 어디까지 사용할까

- [참조 조립 생성기](../reference-parts/RC_CAR_Reference_Assembly_Builder.py): 빠른 배치 개념 확인용이다. 일부 외곽은 파라미터로 연결되지만 부품 위치와 여러 치수는 고정 수치다. 예를 들어 ESP32·TB6612 외곽 생성은 등록된 길이·폭 파라미터 대신 수치를 직접 사용한다. 현재 코드에서 모터 축과 바퀴 축 방향도 실제 동축 조립을 표현하지 않으므로 완성된 구동계 조립체로 사용하지 않는다.
- [기본 차체 생성기](RC_CAR_Chassis_Frame_Builder.py): 차체 형태를 살펴보는 시작점이다. 기본 외곽은 실측 부품에서 산출한 결과가 아니다.
- [장착 프레임 생성기](RC_CAR_Mounting_Frame_Builder.py): 장착 구조의 참고안이다. 실측한 브래킷 홀·모터 축·배터리 크기에 맞춰 검토해야 한다.
- [로버 생성기](RC_CAR_Rover_Chassis_Builder.py): 큰 차체와 상부 데크 구조의 참고안이다. 실제 프린터 크기와 필요한 부품 배치에서 차체 크기를 다시 결정한다.

이번 실습의 첫 결과물은 **실측한 모터 + 바퀴 + 브래킷 한 세트와, 시험 출력한 마운트 한 개**로 잡는다. 이 체결이 맞은 뒤 나머지 부품 배치와 전체 차체로 진행한다.

[전체 부품표](../../parts/BOM.md) · [v4 구매 규격](../../parts/purchasing/v4.md) · [v4 실습](../../v4/README.md) · [하드웨어 안내](../README.md)

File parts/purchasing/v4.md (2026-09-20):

# v4 추가 구매 목록 — 2구동륜 엔코더 N20 속도 제어

v0의 TT 모터를 좌우 N20 엔코더 모터 2개로 교체하는 확장입니다. 뒤쪽에는 자유회전 수동 바퀴 2개를 사용하며, 기존 TT 모터와 드라이버는 v0 실습용으로 보관합니다.

| 분류 | 구매 부품 | 수량 | 선택 기준 | AliExpress 검색어 | 확인한 상품 URL |
| --- | --- | ---: | --- | --- | --- |
| 구동 | 엔코더 포함 N20 메탈 기어드모터 | 2 | 6 V, 약 100 RPM, 엔코더 A/B 출력, 좌우 같은 옵션 | `N20 encoder metal gear motor 6V 100RPM` | 구매 전 기록 |
| 구동 | N20용 고무 바퀴 | 2 | 실제 출력축 규격(보통 3 mm D축)과 일치 | `N20 3mm D shaft rubber wheel` | 구매 전 기록 |
| 지지 | 자유회전 수동 바퀴 | 2 | N20 바퀴와 접지 높이가 맞고 차체에 장착 가능 | `passive caster wheel robot 70mm` | 구매 전 기록 |
| 조립 | N20 금속 브래킷 | 2 | 모터 본체 치수와 고정홀에 맞춤 | `N20 metal motor bracket` | 구매 전 기록 |
| 구동 | TB6612FNG 모터 드라이버 | 1 | 2채널 보드 1개, 좌우 모터에 한 채널씩 사용 | `TB6612FNG motor driver module` | 구매 전 기록 |
| 신호 | 10 kΩ 저항 | 최대 2 | 필요 시 좌우 엔코더 A 신호의 3.3 V 풀업 | `10K ohm resistor kit` | 구매 전 기록 |
| 보호 | 470 uF 이상 16 V 전해 커패시터 | 1 | TB6612FNG VM-GND 근처 | `470uF 16V electrolytic capacitor` | 구매 전 기록 |

상품 상세에서 엔코더 로직 전압이 3.3 V와 호환되는지, A/B 채널이 외부로 나오는지, 정지전류가 드라이버 채널 허용 전류보다 작은지 확인합니다.

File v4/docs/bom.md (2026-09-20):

# v4 추가 부품표

| 부품 | 수량 | 역할 |
| --- | ---: | --- |
| 6 V 엔코더 포함 N20 메탈 기어드모터 | 2 | 좌우 구동과 속도 측정 |
| 3 mm D축 호환 구동 바퀴 | 2 | N20 출력축과 결합 |
| 자유회전 수동 바퀴 | 2 | 뒤쪽 지지와 접지 |
| N20 금속 모터 브래킷 | 2 | 3D 프린팅 샤시에 모터 고정 |
| TB6612FNG 모터 드라이버 | 1 | 좌우 모터를 두 채널로 제어 |
| 10 kΩ 저항 | 최대 2 | 필요 시 좌우 엔코더 A 신호의 3.3 V 풀업 |
| 470 uF 이상 전해 커패시터 | 1 | TB6612FNG의 VM-GND 근처 노이즈 완화 |

v0의 ESP32, AA 배터리 4개, 5 V 벅-부스트 컨버터와 v1의 VL53L1X를 그대로 사용합니다. 조종기 쪽은 별도 1셀 배터리, 보호·충전 회로, 3.3 V 레귤레이터를 준비합니다.

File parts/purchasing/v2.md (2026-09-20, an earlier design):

# v2 추가 구매 목록 — ESP-NOW 조이스틱 조종기

v1 차량은 그대로 사용하고, 별도 휴대 조종기를 만듭니다.

| 분류 | 구매 부품 | 수량 | 선택 기준 | AliExpress 검색어 | 확인한 상품 URL |
| --- | --- | ---: | --- | --- | --- |
| 제어 | ESP32 DevKit V1 | 1 | 차량용과 같은 계열 권장 | `ESP32 DevKit V1 ESP32-WROOM-32` | 구매 전 기록 |
| 입력 | 2축 아날로그 조이스틱 모듈 | 1 | VRx, VRy, SW 핀, 3.3 V 구동 | `PS2 joystick module analog 3.3V` | 구매 전 기록 |
| 입력 | 푸시 버튼 | 1 | 정지용, 캡 포함 선택 가능 | `momentary push button switch 12mm` | 구매 전 기록 |
| 전원 | 1셀 배터리 보호·충전 모듈 + 3.3V 레귤레이터 | 1세트 | 조종기 ESP32에 안정적인 3.3 V 공급, 셀 화학계열과 충전 전압 일치 | `1S Li-ion charger 3.3V regulator` | 구매 전 기록 |
| 조립 | M3 나사·히트셋 인서트 | 1세트 | 3D 프린팅 조종기 케이스 체결용 | `M3 heat set insert screw kit` | 구매 전 기록 |

조종기 케이스는 3D 프린팅합니다. 조종기 전원은 보호·충전된 1셀 배터리를 3.3V 레귤레이터에 연결합니다. 일반 Li-ion 셀을 ESP32 3V3에 직접 연결하지 않습니다. ESP32 안테나가 금속·배터리·두꺼운 벽에 가려지지 않도록 케이스 상단 또는 가장자리에 배치합니다.

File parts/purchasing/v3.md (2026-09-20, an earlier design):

# v3 추가 구매 목록 — BMI270 핸드 제스처 조종기

v2 조종기 케이스와 ESP32를 재사용하고 BMI270만 추가합니다.

| 분류 | 구매 부품 | 수량 | 선택 기준 | AliExpress 검색어 | 확인한 상품 URL |
| --- | --- | ---: | --- | --- | --- |
| 센서 | BMI270 브레이크아웃 모듈 | 1 | BMI270 칩, I2C 지원, 3.3 V 로직 | `BMI270 IMU sensor I2C breakout` | 구매 전 기록 |
| 배선 | 4핀 I2C 케이블 또는 점퍼선 | 1세트 | VCC, GND, SDA, SCL 연결 | `4 pin I2C cable dupont` | 구매 전 기록 |
| 조립 | M2 또는 M3 나사·스페이서 | 1세트 | 실제 BMI270 보드 고정홀을 확인 | `M2 M3 nylon standoff screw kit` | 구매 전 기록 |
| 전원 | 1셀 배터리 보호·충전 모듈 + 3.3V 레귤레이터 | 1세트 | ESP32 순간 전류 여유, 셀 화학계열과 충전 전압 일치 | `1S Li-ion charger 3.3V regulator` | 구매 전 기록 |

BMI270은 조종기 케이스의 중심에 단단히 고정합니다. 손의 기울기를 측정하므로 헐겁게 장착하면 제스처 값이 흔들립니다. 일반 Li-ion 셀의 원전압을 ESP32 3V3에 직접 연결하지 않고 보호·충전 회로와 3.3V 레귤레이터를 사용합니다.

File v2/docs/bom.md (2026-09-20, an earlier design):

# v2 추가 부품

| 부품 | 수량 | 역할 |
|---|---:|---|
| ESP32 DevKit V1 | 1 | 조종기 |
| 2축 조이스틱 | 1 | 전후진·조향 |
| 정지 버튼 | 1 | GPIO 4, 눌림 LOW |
| 1셀 Li-ion/LiPo + 보호·충전 + 3.3V 레귤레이터 | 1세트 | 조종기 ESP32 전원. 셀을 3V3에 직접 연결하지 않음 |
| v1 차량 | 1 | 무선 수신·거리 안전 |

속도 모드 버튼은 기본 구현에 포함하지 않는다. [전체 BOM](../../parts/BOM.md)

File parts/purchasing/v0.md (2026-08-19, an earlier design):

# v0 구매 목록 — 3D 프린팅 2WD RC카

v0에서 차량을 처음 만들기 위해 구매하는 목록입니다. 샤시·배터리 트레이·센서 마운트는 3D 프린팅하고, 모터·바퀴·전자부품은 기성품을 사용합니다.

| 분류 | 구매 부품 | 수량 | 선택 기준 | AliExpress 검색어 | 확인한 상품 URL |
| --- | --- | ---: | --- | --- | --- |
| 제어 | ESP32 DevKit V1 | 1 | ESP32-WROOM-32, Micro-USB 또는 USB-C | `ESP32 DevKit V1 ESP32-WROOM-32` | 구매 전 기록 |
| 구동 | TT DC 기어드모터 | 2 | 3~6 V, 동일 RPM·축 규격 한 쌍 | `TT motor 3-6V DC gear motor 2pcs` | 구매 전 기록 |
| 구동 | TT 모터용 바퀴 | 2 | TT D축 호환, 고무 타이어 권장 | `TT motor wheel rubber tire 65mm` | 구매 전 기록 |
| 구동 | 볼 캐스터 | 1 | 뒤쪽 보조 바퀴, 20~25 mm급 | `mini ball caster wheel robot` | 구매 전 기록 |
| 구동 | TB6612FNG 모터 드라이버 | 1 | 2채널, STBY 핀이 있는 브레이크아웃 | `TB6612FNG motor driver module` | 구매 전 기록 |
| 전원 | AA 알카라인 배터리 | 4 | 충전하지 않는 동일 브랜드·동일 새 제품 | `AA alkaline battery 1.5V 4pcs` | 구매 전 기록 |
| 전원 | 4칸 AA 배터리 홀더 | 1 | 직렬 6 V 출력, 스위치 포함 권장 | `4 AA battery holder switch 6V` | 구매 전 기록 |
| 전원 | 5 V 2 A 이상 벅-부스트 컨버터 | 1 | 입력 약 3.5~7 V, ESP32 5 V/VIN 전원용 | `DC DC buck boost converter 5V 2A` | 구매 전 기록 |
| 전원 | 로커 스위치 | 1 | 6 V DC·예상 전류를 견디는 제품, 홀더에 스위치가 없을 때 | `mini rocker switch 6V DC` | 구매 전 기록 |
| 보호 | 470 uF 이상 전해 커패시터 | 1 | 16 V 이상, TB6612 VM 근처 설치 | `470uF 16V electrolytic capacitor` | 구매 전 기록 |
| 배선 | 전선·점퍼선 세트 | 1세트 | 전원은 22~24 AWG, 신호는 점퍼선 | `silicone wire 22AWG jumper wire kit` | 구매 전 기록 |
| 조립 | 2핀 커넥터 세트 | 1세트 | 배터리 홀더·전원모듈 연결용 | `2 pin connector kit JST` | 구매 전 기록 |
| 조립 | M3 나사·너트·스페이서 | 1세트 | M3 x 6/8/12 mm 중심 | `M3 screw nut standoff assortment` | 구매 전 기록 |
| 조립 | M3 황동 히트셋 인서트 | 1세트 | 3D 프린팅 부품의 반복 체결용 | `M3 heat set insert brass` | 구매 전 기록 |
| 3D 프린팅 | PETG 필라멘트 | 1롤 | 차량 하부 샤시·모터 마운트용 | `PETG filament 1.75mm` | 구매 전 기록 |
| 3D 프린팅 | TPU 필라멘트 (선택) | 1롤 | 전면 범퍼·미끄럼 방지 부품용 | `TPU filament 1.75mm 95A` | 구매 전 기록 |

## 구매 전 확인

- TT 모터의 실제 길이·폭·고정홀·축 형상을 측정한 뒤 3D 모델 치수를 결정합니다.
- 알카라인 AA 배터리는 충전하지 않습니다. 4개를 한 세트로 사용하고, 전압이 낮아지면 4개를 함께 교체합니다.
- AA 배터리팩은 TB6612FNG의 VM으로 연결하고, ESP32에는 5 V 벅-부스트 컨버터를 거쳐 공급합니다.
- 배터리와 TB6612FNG, ESP32의 GND는 공통으로 연결합니다.

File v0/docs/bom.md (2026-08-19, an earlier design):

# 부품표 (RC Car v0)

| 분류 | 부품 | 수량 | 비고 |
| --- | --- | ---: | --- |
| 제어 | ESP32 DevKit | 1 | Wi-Fi 제어 확장 가능 |
| 구동 | TT 6 V DC 기어드모터 | 2 | 동일 RPM·축 규격의 한 쌍 |
| 구동 | TT 모터용 바퀴와 볼 캐스터 | 2개, 1개 | 3D 프린팅 샤시와 조합 |
| 구동 | TB6612FNG 모터 드라이버 모듈 | 1 | 좌·우 모터 독립 제어 |
| 전원 | AA 알카라인 배터리 | 4 | 충전하지 않는 동일 새 배터리 |
| 전원 | 4칸 AA 배터리 홀더 | 1 | 직렬 6 V 출력, 스위치 포함 권장 |
| 전원 | 5 V 2 A 이상 벅-부스트 컨버터 | 1 | ESP32 전원 |
| 보호 | 470 uF 전해 커패시터 | 1 | 모터 드라이버 전원 근처 |
| 기타 | 스위치, 전선, 점퍼선 | 필요량 | 전원과 신호 배선 |

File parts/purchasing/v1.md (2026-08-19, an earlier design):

# v1 추가 구매 목록 — 거리 감지와 안전 정지

v0 차량을 완성했다는 전제에서 추가 구매하는 부품입니다.

| 분류 | 구매 부품 | 수량 | 선택 기준 | AliExpress 검색어 | 확인한 상품 URL |
| --- | --- | ---: | --- | --- | --- |
| 센서 | VL53L1X ToF 거리 센서 모듈 | 1 | I2C, 3.3 V 로직 호환, VL53L1X 칩 표기 | `VL53L1X ToF distance sensor I2C module` | 구매 전 기록 |
| 배선 | 4핀 I2C 케이블 또는 점퍼선 | 1세트 | VCC, GND, SDA, SCL 연결 | `4 pin I2C cable dupont` | 구매 전 기록 |
| 조립 | M3 나사·스페이서 (필요 시) | 1세트 | 전면 센서 브래킷 고정용 | `M3 nylon standoff screw` | 구매 전 기록 |

센서 브래킷과 전면 범퍼는 3D 프린팅합니다. 센서 앞쪽에 커버·범퍼가 거리 측정 영역을 가리지 않도록 배치합니다.

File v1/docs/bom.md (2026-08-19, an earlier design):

# v1 부품표

| 부품 | 수량 | 역할 |
| --- | ---: | --- |
| v0 RC카 전체 | 1 | 차량·모터·ESP32 기반 |
| VL53L1X ToF 거리센서 모듈 | 1 | 전방 거리 측정 |
| 4핀 I2C 케이블 또는 점퍼선 | 1 | 3.3 V, GND, SDA, SCL 연결 |

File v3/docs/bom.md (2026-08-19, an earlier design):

# v3 부품표

| 부품 | 수량 | 역할 |
| --- | ---: | --- |
| v2 조종기 | 1 | ESP-NOW 송신·정지 버튼 |
| BMI270 브레이크아웃 모듈 | 1 | 손 기울기·각속도 측정 |
| 4핀 I2C 케이블 또는 점퍼선 | 1 | BMI270 연결 |
| v2 차량 | 1 | 명령 수신·안전 제어 |

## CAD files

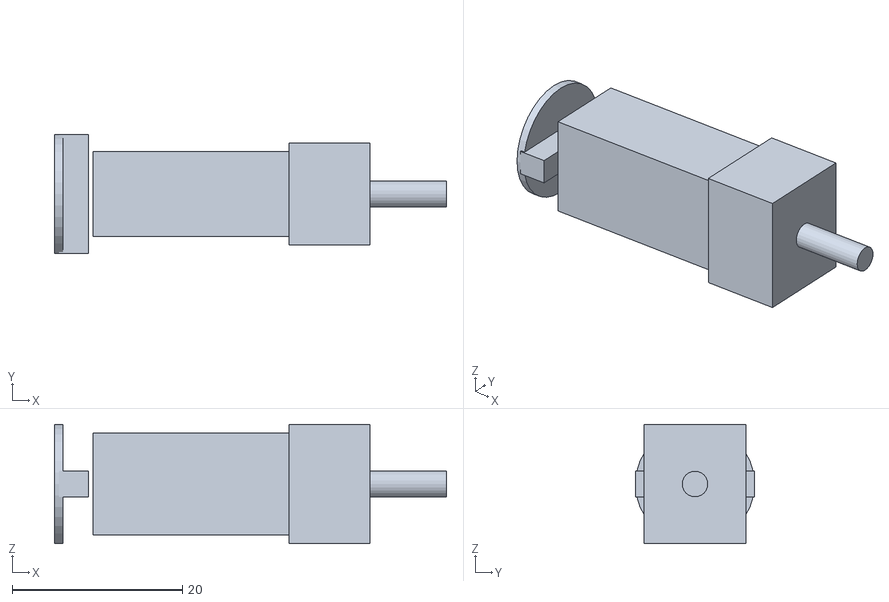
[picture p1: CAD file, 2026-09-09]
hardware/reference-parts/N20_encoder_motor_reference.stl
46.0 x 14.0 x 14.0

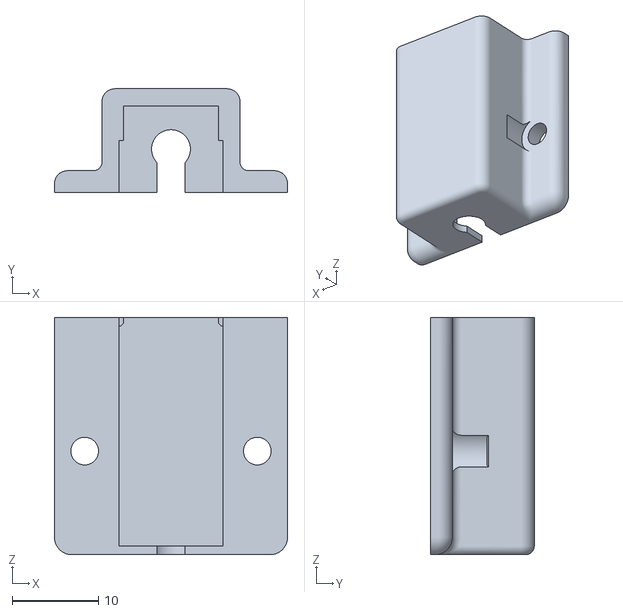
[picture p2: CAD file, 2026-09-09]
hardware/stl/N20withEncoder_mount.stl
27.0 x 12.0 x 27.5

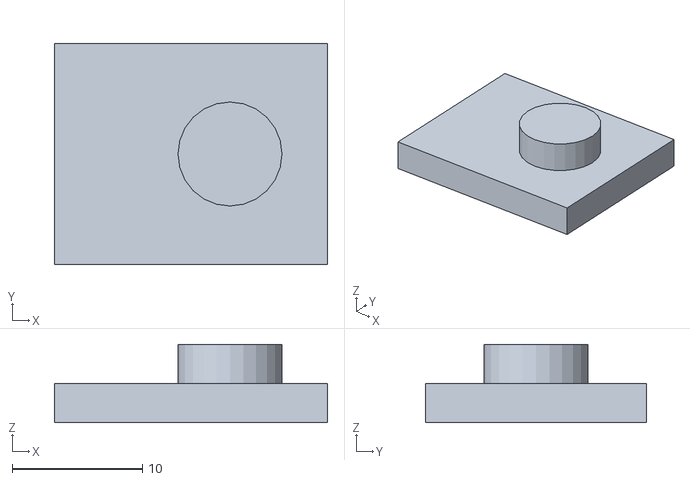
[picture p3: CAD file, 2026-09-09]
hardware/reference-parts/VL53L1X_reference.stl
21.0 x 17.0 x 6.00

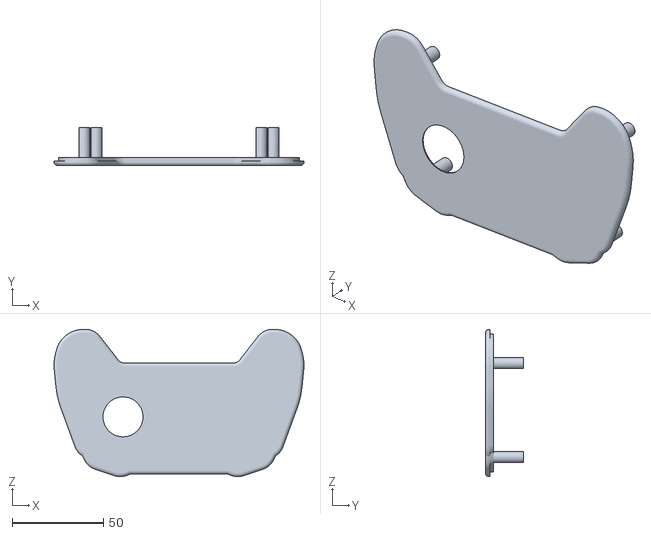
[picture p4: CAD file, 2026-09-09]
hardware/stl/controller-top.STL
137.3 x 21.0 x 80.9

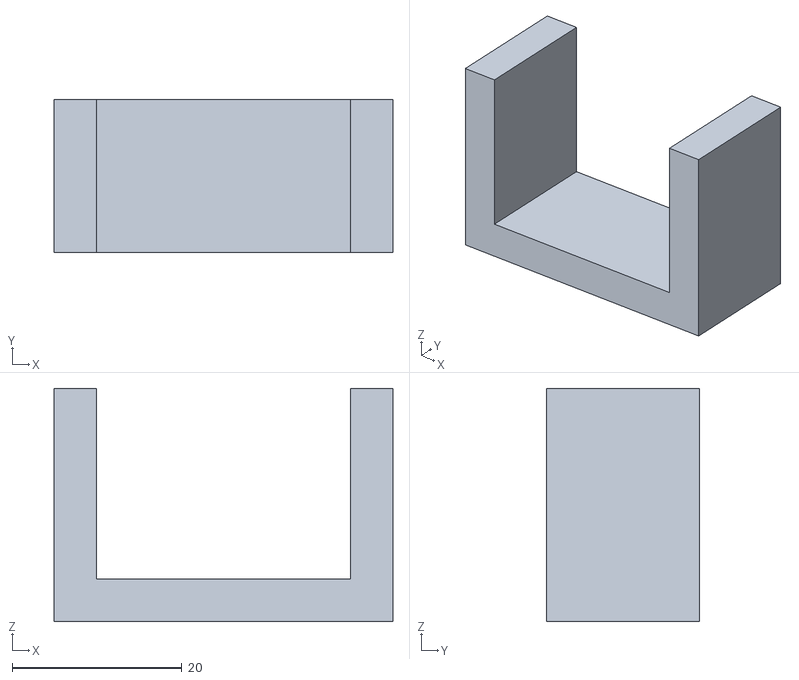
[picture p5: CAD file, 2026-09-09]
hardware/reference-parts/N20_motor_bracket_reference.stl
40.0 x 18.0 x 27.5

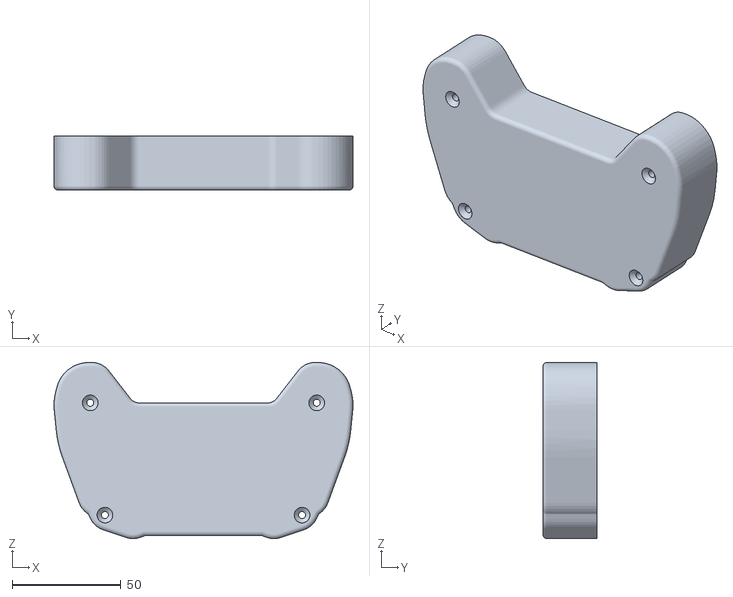
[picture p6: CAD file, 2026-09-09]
hardware/stl/controller-bottom.STL
137.3 x 25.0 x 80.9

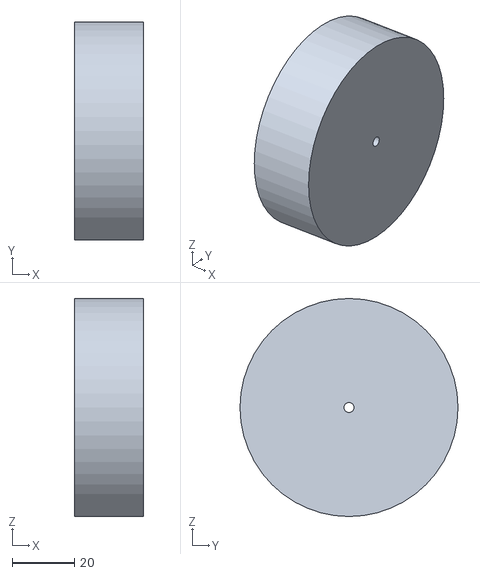
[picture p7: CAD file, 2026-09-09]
hardware/reference-parts/wheel_70mm_reference.stl
22.0 x 70.0 x 70.0

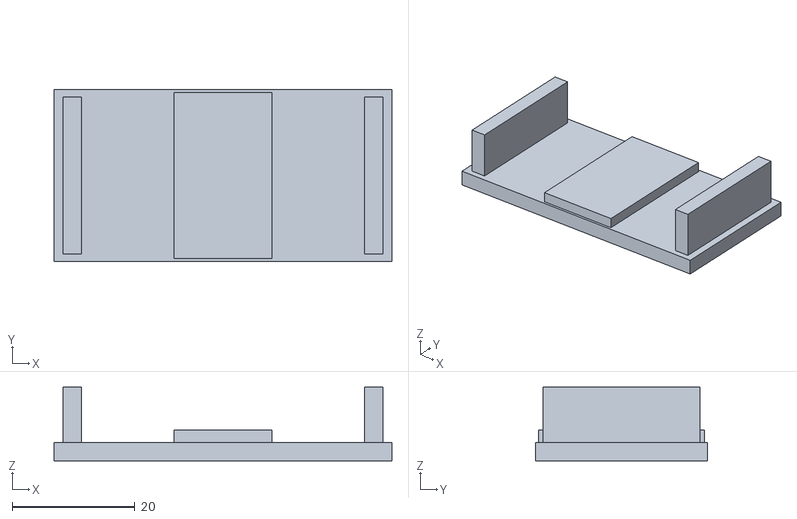
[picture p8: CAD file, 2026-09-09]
hardware/reference-parts/ESP32_DevKit_V1_reference.stl
55.0 x 28.0 x 12.0

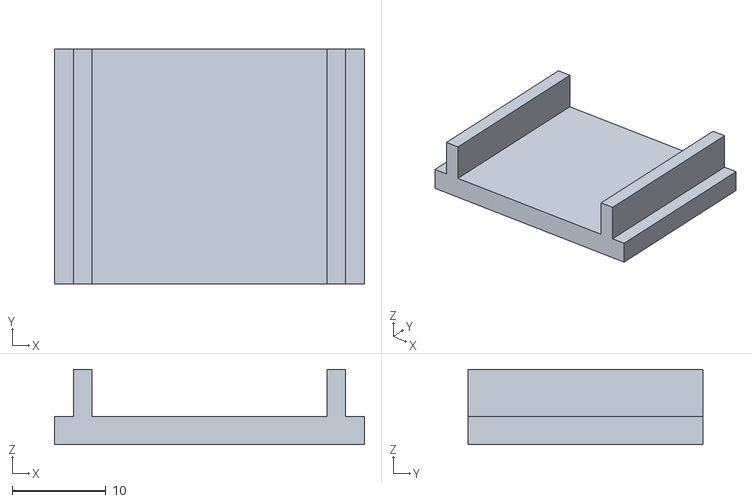
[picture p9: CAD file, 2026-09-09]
hardware/reference-parts/TB6612FNG_breakout_reference.stl
33.0 x 25.0 x 8.00

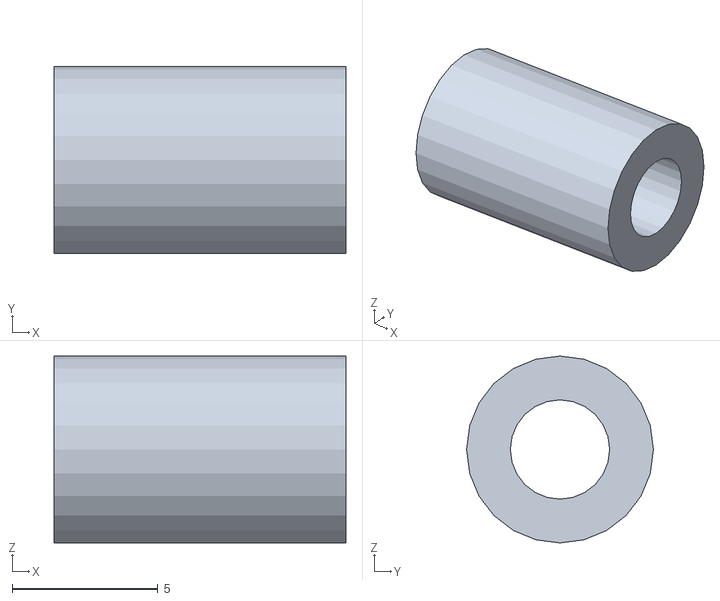
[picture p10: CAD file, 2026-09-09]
hardware/reference-parts/M3_spacer_10mm_reference.stl
10.0 x 6.40 x 6.40

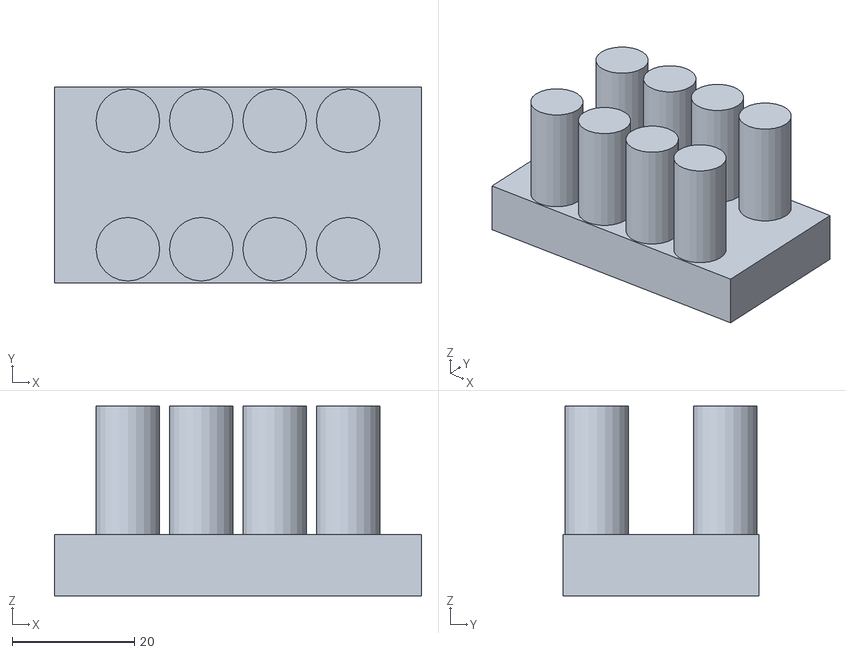
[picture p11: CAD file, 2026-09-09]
hardware/reference-parts/AA_4cell_holder_reference.stl
60.0 x 32.0 x 31.0

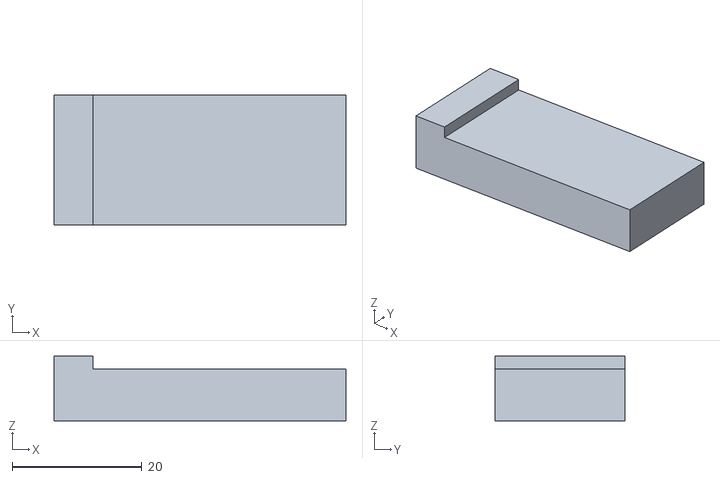
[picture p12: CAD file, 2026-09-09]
hardware/reference-parts/buck_converter_reference.stl
45.0 x 20.0 x 10.0

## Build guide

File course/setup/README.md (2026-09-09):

# 설치와 업로드 준비

이 저장소의 핀맵은 일반 ESP32 DevKit V1 / ESP32-WROOM-32 기준이다. ESP32-C3/S3 등 다른 보드는 GPIO와 기능을 별도로 확인해야 한다.

| 설치 항목 | 사용 단계 | 안내 |
|---|---|---|
| Arduino IDE와 ESP32 보드 패키지 | 전체 | [ESP32 설치](esp32-board-package.md) |
| Pololu VL53L1X | v1, v2 차량, v4 차량 | [거리센서 라이브러리](vl53l1x-pololu.md) |
| SparkFun BMI270 Arduino Library | v3 | [IMU 라이브러리](bmi270-sparkfun.md) |
| ESP-NOW | v2, v3, v4 | [통신 설정](esp-now.md) |
| Fusion 360 | 선택 차체 설계 실습 | [설계 파일](../../hardware/README.md) |

## 업로드

1. Arduino IDE에서 보드를 ESP32 Dev Module로 선택한다.
2. USB 포트를 확인하고 모터 전원을 끈다.
3. 해당 스케치 폴더의 같은 이름 .ino 파일을 연다. v0~v4 전체를 하나의 스케치로 합치지 않는다.
4. 컴파일 후 해당 보드에 업로드한다.
5. 시리얼 출력이 있는 실습은 Arduino IDE의 시리얼 모니터를 115200 baud로 연다. f/b/l/r/s 같은 명령은 입력창에서 한 글자씩 전송한다.
6. 모터를 시험하기 전 배선표와 실제 연결을 비교한다.

무선 단계에서는 송신기와 수신기에 서로 다른 코드를 올린다. [장비별 설정](../CONFIGURATION.md)에 따라 차량 MAC 주소를 입력한다. 실습 언어와 라이브러리 호출의 구분은 [C언어 중심 안내](../ARDUINO_C_GUIDE.md)를 따른다.

공식 설치 안내: [Espressif Arduino ESP32](https://docs.espressif.com/projects/arduino-esp32/en/latest/installing.html).

## 컴파일 확인 환경

수업 코드의 컴파일 확인에는 `ESP32 Dev Module`, ESP32 보드 패키지 `2.0.11`, Pololu VL53L1X `1.3.1`, SparkFun BMI270 Arduino Library `1.0.3`을 사용한다. ESP32 3.x용 수신 콜백 분기도 코드에 포함되어 있지만 전체 스케치의 보드 컴파일 확인은 2.0.11 기준이다. 실제 장비의 업로드·배선·주행 결과는 별도로 실습 기록에 남긴다.

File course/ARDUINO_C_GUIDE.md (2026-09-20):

# Arduino에서 배우는 C언어 중심 RC카 실습

수업은 **ESP32 + Arduino IDE + 시리얼 모니터**로 진행한다. 기존 ESP32 DevKit의 배선과 부품을 사용한다. Arduino IDE를 쓴다고 보드를 Arduino Uno로 바꾸는 것은 아니다.

## 언어와 라이브러리의 구분

학생이 작성하는 제어 로직은 C 문법으로 설명한다. `int`, `float`, `const`, `if`, `switch`, `for`, 함수, 배열, `typedef struct`, 포인터를 순서대로 배운다. 직접 클래스를 만들거나 상속·템플릿을 배우는 과정은 포함하지 않는다.

Arduino의 `.ino` 파일은 전처리 후 C++로 컴파일된다. 이 저장소는 **C 문법 중심의 Arduino 스케치**이며 순수 ISO C 프로그램은 아니다. `Serial.begin()`, `Wire.begin()`, `tof.read()`, `bmi.getSensorData()`는 Arduino와 센서 라이브러리가 제공하는 C++ API다. 이 호출부는 장치와 데이터를 주고받는 방법으로 설명하고, 학생은 반환값을 이용해 판단·계산·출력을 작성한다. [Arduino 공식 빌드 과정](https://docs.arduino.cc/arduino-cli/sketch-build-process/)

`.ino` 확장자를 `.c`로 바꾸지 않는다. Arduino API를 사용하는 현재 스케치를 그대로 Arduino IDE에서 열고 **ESP32 Dev Module**을 선택한다. Fusion 360 폴더의 Python은 설계 도구이며 차량 코딩 실습과 별개다.

## 단계별 C 문법과 수정 과제

| 단계 | 먼저 설명할 문법 | 코드에서 읽을 부분 | 학생이 직접 바꿀 내용 | 확인할 결과 |
|---|---|---|---|---|
| [v0](../v0/README.md) | 자료형, 상수, 함수·인자, if/else, switch, break, return | `setMotor()`, `drive()`, 명령 분기 | `DRIVE_SPEED`를 120과 180으로 바꾸고 방향별 인자를 설명 | PWM과 실제 속도 차이, f/b/l/r/s 동작 |
| [v1](../v1/README.md) | bool, 비교·논리 연산, while, 상태 변수, unsigned long | `currentCommand`, `updateDistance()`, `obstacleTooClose()` | `STOP_MM`를 300으로 바꾸고 경계값 조건을 설명 | 한 번 f를 보내도 거리 변화로 정지하는지, 새 f 전까지 정지 유지 |
| [v2](../v2/README.md) | 배열, typedef struct, 고정 폭 정수, 주소 &, sizeof, memcpy, 콜백 함수 | `ControlPacket`, `axisToCommand()`, `onReceive()` | 조이스틱 데드존을 120에서 200으로 변경 | 중립 흔들림, 버튼 정지, 통신 끊김 후 정지 |
| [v3](../v3/README.md) | float 계산, fabsf/atan2/sqrt, for 누적·평균, 형 변환 | `angleToCommand()`, `calibrateNeutral()` | 데드존 8도와 12도를 비교하고 100회 평균 계산 설명 | 기울기→명령의 변화, 부팅 시 중립 보정 |
| [v4](../v4/README.md) | 배열 인덱스, volatile, ISR, 임계 구역, 시간 차, 누적값 | `pulses[]`, `updatePid()`, P/I/D 계산 | 좌우 구동륜 1회전 펄스를 실측해 PPR 입력, Kp부터 조정 | 좌우 RPM 기록, 목표값과 오차·진동 비교 |

`map()`, `constrain()`, `millis()`는 Arduino 함수·매크로다. `fabsf()`, `atan2()`, `sqrt()`는 C 수학 함수다. `bool`은 C99의 `<stdbool.h>`, `int16_t`·`uint32_t`는 `<stdint.h>`와 연결해 설명한다. `volatile`만으로 동시 접근이 안전해지지 않으므로 v4에서는 인터럽트와 공유하는 값을 임계 구역에서 복사하는 이유도 다룬다.

## 첫 코드 읽기: 변수 → 함수 → 명령 분기

다음은 [v0 기본 주행](../v0/firmware/02_basic_drive/02_basic_drive.ino)의 일부다. 전체 실행에는 해당 스케치의 핀 설정과 함수가 필요하다.

```c
const int DRIVE_SPEED = 180;

void drive(int leftSpeed, int rightSpeed) {
  setMotor(AIN1, AIN2, PWMA, leftSpeed);
  setMotor(BIN1, BIN2, PWMB, rightSpeed);
}
```

`const int`는 바꾸지 않을 정수 값을 선언한다. `void`는 반환값이 없다는 뜻이고 두 인자는 왼쪽·오른쪽 모터 명령이다. 양수는 전진, 음수는 후진, 0은 정지로 처리한다. `loop()`의 `switch`에서 문자 명령마다 이 함수를 다른 인자로 호출한다.

초반에는 `pinMode()`를 핀마다 작성해 입출력을 익힌다. v2에서는 MAC 주소와 패킷으로 배열·구조체를 배우고, v4에서 좌우 두 구동축을 배열 인덱스로 처리한다. 뒤 수동 바퀴에는 제어 신호나 엔코더를 연결하지 않는다.

## 무선 코드 읽기: 구조체 → 주소 → 전송

아래는 송신기의 일부다. `ControlPacket` 선언과 ESP-NOW 초기화는 [v2 조이스틱 조종기](../v2/firmware/controller_joystick/controller_joystick.ino)에 있다.

```c
ControlPacket packet = {0};
packet.throttle = axisToCommand(analogRead(JOY_Y));
packet.steering = axisToCommand(analogRead(JOY_X));
packet.emergencyStop = !digitalRead(STOP_BUTTON);
packet.sequence = sequenceNumber++;

esp_now_send(vehicleMac, (const uint8_t *)&packet, sizeof(packet));
```

`packet.throttle`은 구조체 필드 접근이고, `tof.read()`는 센서 객체의 기능 호출이다. 같은 점 표기가 나오지만 역할이 다르다. `&packet`은 메모리 주소, `(const uint8_t *)`는 그 주소를 읽기 전용 바이트 포인터로 전달하는 형 변환, `sizeof(packet)`은 패딩을 포함한 구조체 크기다. 송신기·수신기의 필드 순서와 자료형을 함께 유지한다. 이 원시 구조체 전송은 같은 ESP32 환경을 전제로 하며 다른 기종 간의 범용 데이터 형식으로 설명하지 않는다.

## 실행과 결과 확인

1. 각 버전 README의 표에서 단품 스케치를 먼저 연다. `.ino` 파일과 폴더 이름을 같게 유지한다.
2. [설치 안내](setup/README.md)에 따라 컴파일하고 해당 ESP32에 업로드한다.
3. 시리얼 모니터를 115200 baud로 연다. 명령 입력은 한 글자씩 전송한다.
4. 한 번에 설정 하나를 바꾸고 예상 결과와 실제 측정값을 [실습 기록](LAB_RECORD.md)에 적는다.
5. 통합 스케치로 이동해 기존 동작과 정지 조건을 다시 확인한다.

v0 단품 모터 테스트는 자동으로 전후진한다. 모든 모터 실습의 첫 시험은 바퀴를 띄운 상태에서 진행한다. v1·v2·v4 통합 차량은 거리 값이 없거나 오래된 경우에도 전진을 차단한다. v4의 `PULSES_PER_WHEEL_REV = 1.0f`는 실측 전 자리값이므로 보정 없이 RPM 정확도를 평가하지 않는다.

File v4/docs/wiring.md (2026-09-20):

# v4 배선

## 전원

```text
AA 배터리 4개 (+) → 스위치 → TB6612FNG VM
AA 배터리 4개 (-) ─────────→ 드라이버 GND와 차량 ESP32 GND
AA 배터리 4개 → 5 V 벅-부스트 → ESP32 5V/VIN
ESP32 3V3 → TB6612FNG VCC/STBY, VL53L1X, 좌우 엔코더 로직 전원(3.3 V 호환 시)
```

`STBY`는 ESP32 `3V3`에 연결해 활성화합니다. 드라이버의 VM-GND 가까이에 470 uF 이상 커패시터를 둡니다. AA 팩은 공칭 6 V라서 6 V N20의 VM 후보가 되지만, 실제 N20 정지전류가 드라이버와 AA 셀의 허용 범위 안인지 확인해야 합니다.

## 모터 드라이버와 엔코더

| 위치 | TB6612FNG 채널 | IN1 | IN2 | PWM | 엔코더 A |
| --- | --- | ---: | ---: | ---: | ---: |
| 좌측 구동 (기본 FL) | A | GPIO 18 | GPIO 19 | GPIO 13 | GPIO 34 |
| 우측 구동 (기본 FR) | B | GPIO 23 | GPIO 25 | GPIO 14 | GPIO 35 |
| 뒤쪽 수동 바퀴 RL/RR | 연결 없음 | - | - | - | - |

각 엔코더의 GND는 차량 ESP32 GND, VCC는 제품 사양에 맞는 3.3 V에 연결합니다. A 채널만 GPIO 34/35에 연결합니다. 이 GPIO는 입력 전용이며 내부 풀업이 없으므로, 엔코더가 오픈 컬렉터 출력이면 각 A 신호와 3.3 V 사이에 10 kΩ 풀업 저항을 추가합니다. 수동 바퀴에는 전선이나 엔코더를 연결하지 않습니다.

## 조종기 전원

v2 조이스틱 조종기와 v3 BMI270 조종기는 차량과 별도 배터리를 사용합니다. 일반 1셀 Li-ion/LiPo는 공칭 3.6~3.7 V, 완충 4.2 V이므로 ESP32의 3V3 핀에 직접 연결하지 않습니다. 보호·충전 회로와 3.3 V 레귤레이터(ESP32 순간 전류 여유 포함)를 거친 출력만 ESP32와 BMI270에 공급합니다. ESP-NOW 링크이므로 차량과 조종기 사이에 전원 GND를 따로 연결할 필요는 없고, 각 장치 내부의 GND는 공통으로 연결합니다.

VL53L1X는 이전과 동일하게 SDA GPIO 21, SCL GPIO 22를 사용합니다.

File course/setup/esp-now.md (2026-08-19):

# ESP-NOW

## 사용하는 곳

- v2 조이스틱 조종기와 차량
- v3 BMI270 제스처 조종기와 차량
- v4 엔코더 N20 차량 수신기

## 설치 여부

별도 라이브러리 설치는 필요 없습니다. `esp_now.h`와 `WiFi.h`는 [ESP32 보드 패키지](esp32-board-package.md)에 포함됩니다.

## 사전 확인

1. 차량과 조종기 모두 ESP32 보드 패키지를 설치한다.
2. `v2/firmware/00_print_mac`을 각 보드에 업로드해 MAC 주소를 기록한다.
3. 송신 코드의 `vehicleMac` 배열에 차량 ESP32의 MAC 주소를 입력한다.
4. 통신 실습은 v2의 송신·수신 테스트 코드부터 진행한다.

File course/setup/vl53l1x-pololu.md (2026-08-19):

# VL53L1X by Pololu

## 사용하는 곳

- v1 `01_distance_read`
- v1 `02_safety_stop`
- v2 차량 수신기
- v3 차량 수신기 (v2 코드 재사용)
- v4 차량 수신기

## 설치

1. Arduino IDE에서 `스케치 > 라이브러리 포함하기 > 라이브러리 관리`를 연다.
2. `VL53L1X`를 검색한다.
3. 제작자가 `Pololu`인 **VL53L1X**를 설치한다.

## 확인

`v1/firmware/01_distance_read/01_distance_read.ino`를 먼저 업로드해 거리 값이 출력되는지 확인한 뒤 안전 정지 실습으로 넘어갑니다.

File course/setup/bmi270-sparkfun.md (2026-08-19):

# SparkFun BMI270 Arduino Library

## 사용하는 곳

- v3 `00_bmi270_read`
- v3 `01_gesture_map_test`
- v3 `controller_bmi270`

## 설치

1. Arduino IDE에서 `스케치 > 라이브러리 포함하기 > 라이브러리 관리`를 연다.
2. `SparkFun BMI270`을 검색한다.
3. 제작자가 `SparkFun Electronics`인 **SparkFun BMI270 Arduino Library**를 설치한다.

## 확인

`v3/firmware/00_bmi270_read/00_bmi270_read.ino`로 가속도와 자이로 값이 출력되는 것을 확인한 뒤 제스처 실습을 진행합니다.

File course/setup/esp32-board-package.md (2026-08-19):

# ESP32 보드 패키지

## 설치

1. Arduino IDE를 연다.
2. `파일 > 환경설정`에서 추가 보드 매니저 URLs에 Espressif ESP32 보드 매니저 주소를 등록한다.
3. `도구 > 보드 > 보드 매니저`에서 `esp32 by Espressif Systems`를 설치한다.
4. 보드를 `ESP32 Dev Module`로 선택한다.
5. 시리얼 모니터 속도는 `115200 baud`로 설정한다.

## 포함 기능

- `Wire.h`: I2C 센서 통신
- `WiFi.h`: ESP32 Wi-Fi 기능
- `esp_now.h`: ESP-NOW 무선 통신

모터 전원은 업로드 중 끄고 ESP32 USB만 연결합니다.

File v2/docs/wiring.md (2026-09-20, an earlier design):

# v2 조종기 배선

| 부품 핀 | 조종기 ESP32 | 설명 |
|---|---|---|
| 조이스틱 VRx | GPIO 34 | 조향 ADC |
| 조이스틱 VRy | GPIO 35 | 전후진 ADC |
| 조이스틱 VCC/GND | 3.3V/GND | ADC 입력이 3.3V를 넘지 않도록 연결 |
| 정지 버튼 | GPIO 4와 GND | INPUT_PULLUP, 눌림 LOW |

차량은 [v0 모터 배선](../../v0/docs/wiring.md)과 [v1 센서 배선](../../v1/docs/wiring.md)을 유지한다. 조종기의 GPIO 34/35와 v4 차량의 엔코더 GPIO 34/35는 서로 다른 ESP32의 핀이다.

## 조종기 전원

1셀 Li-ion/LiPo는 공칭 3.6~3.7V이고 완충 시 4.2V가 될 수 있다. 보호·충전 회로와 3.3V 레귤레이터를 거친 출력만 조종기 ESP32와 조이스틱에 공급한다. 레귤레이터는 ESP32 무선 송신 순간 전류에 여유가 있어야 한다.

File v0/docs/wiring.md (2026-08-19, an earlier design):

# ESP32와 TB6612FNG 배선

아래 핀은 예시이며, 사용 중인 ESP32 보드와 충돌하지 않는지 확인한 뒤 변경할 수 있습니다.

| TB6612FNG | ESP32 / 전원 | 설명 |
| --- | --- | --- |
| VCC | 3.3 V | 드라이버 로직 전원 |
| VM | AA 배터리 4개 팩 (+) | 모터 전원, 스위치 뒤에서 연결 |
| GND, PGND | 공통 GND | ESP32·모터 전원과 공통 |
| STBY | GPIO 25 | HIGH일 때 드라이버 활성화 |
| AIN1 / AIN2 | GPIO 26 / GPIO 27 | 왼쪽 모터 방향 |
| PWMA | GPIO 14 | 왼쪽 모터 PWM |
| BIN1 / BIN2 | GPIO 32 / GPIO 33 | 오른쪽 모터 방향 |
| PWMB | GPIO 13 | 오른쪽 모터 PWM |
| A01 / A02 | 왼쪽 모터 | 모터 단자 |
| B01 / B02 | 오른쪽 모터 | 모터 단자 |

AA 배터리팩은 TB6612FNG의 VM에 직접 연결하고, 같은 배터리팩을 5 V 벅-부스트 컨버터 입력에도 연결한다. 컨버터의 5 V 출력은 ESP32의 `5V` 또는 `VIN` 핀에 연결한다. 모든 GND는 공통으로 연결한다.

모터 방향이 반대면 모터의 두 선을 서로 바꾸거나 코드의 방향 상수를 반전한다.

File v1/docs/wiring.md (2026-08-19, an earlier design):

# v1 배선

| VL53L1X | 차량 ESP32 | 설명 |
| --- | --- | --- |
| VIN | 3.3 V | 모듈 전원 |
| GND | GND | 공통 접지 |
| SDA | GPIO 21 | I2C 데이터 |
| SCL | GPIO 22 | I2C 클록 |
| XSHUT | 미연결 | 센서 1개일 때 선택 사항 |

센서는 차체 전면을 향하게 고정한다. 모터 배선과 센서 케이블은 가능하면 떨어뜨린다.

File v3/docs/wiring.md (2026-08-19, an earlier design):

# v3 BMI270 조종기 배선

| BMI270 | 조종기 ESP32 | 설명 |
| --- | --- | --- |
| VIN | 3.3 V | 전원 |
| GND | GND | 공통 접지 |
| SDA | GPIO 21 | I2C 데이터 |
| SCL | GPIO 22 | I2C 클록 |
| INT1 | GPIO 27 (선택) | 동작 인터럽트 |

BMI270은 손에 쥐는 조종기 PCB와 단단히 고정한다. 손에 쥘 때의 기준 방향을 README의 제스처 표와 일치시킨다.

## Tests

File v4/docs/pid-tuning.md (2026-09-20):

# PID 튜닝 순서

1. 차체를 받침대에 올려 좌우 구동 바퀴와 수동 바퀴가 바닥에서 떨어지게 한다.
2. `00_encoder_read`에서 모터를 한 바퀴 돌려 `PULSES_PER_WHEEL_REV`를 측정한다.
3. `01_speed_pid_tune`에서 `f`를 보내고 좌우 RPM이 출력되는지 확인한다.
4. 먼저 `Kp`만 조금씩 높여 목표 RPM에 빨리 도달하게 한다.
5. 목표보다 계속 느리거나 빠른 편차가 남으면 `Ki`를 아주 작게 올린다.
6. 진동하거나 PWM이 계속 크게 오르내리면 `Kp` 또는 `Ki`를 낮춘다.
7. 바닥 주행에서 직진 편차가 남으면 모터별 `trim` 값을 0.02씩 조정한다.

처음에는 낮은 목표 RPM으로 시작하고, 모터 발열·배터리 전압·드라이버 발열을 확인한 뒤 속도를 올립니다.

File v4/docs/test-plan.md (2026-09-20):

# v4 테스트 계획

1. 전원을 넣기 전 모든 엔코더 신호가 3.3 V 이하인지 확인한다.
2. `00_encoder_read`에서 좌우 구동 바퀴를 손으로 돌려 해당 채널 펄스만 증가하는지 확인한다. 수동 바퀴에는 펄스가 없어야 한다.
3. 좌우 N20 모터를 차례로 구동해 방향과 RPM 출력을 확인한다.
4. `01_speed_pid_tune`에서 좌우 목표 RPM의 편차를 기록하고 PID·trim을 조정한다.
5. 바닥에서 1 m 직진을 3회 반복해 좌우 편차를 기록한다.
6. v2 또는 v3 조종기로 주행 중 거리 정지와 통신 끊김 정지를 확인한다.

## 전진 감시 추가 시험

- 201mm, 200mm, 199mm 부근에서 전진 허용·차단을 확인한다. 센서 오차가 있으므로 실제 출력값도 기록한다.
- 주행 중 센서 갱신이 끊기면 전진이 차단되는지 확인한다.
- 가까운 장애물에서 후진·제자리 회전이 가능한지 확인한다.

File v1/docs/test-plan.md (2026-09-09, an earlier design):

# v1 검증 순서

1. `01_distance_read`로 거리 출력이 정상인지 확인한다.
2. 1 m, 50 cm, 20 cm 물체에서 출력값을 기록한다.
3. `02_safety_stop`에서 전진 중 20 cm 이내 장애물을 놓는다.
4. 정지 후 후진과 회전은 가능한지 확인한다.
5. 센서 케이블을 분리했을 때 차량이 정지하는지 확인한다.

## 전진 감시 추가 시험

- 201mm, 200mm, 199mm 부근에서 전진 허용·차단을 확인한다. 센서 오차가 있으므로 실제 출력값도 기록한다.
- 주행 중 센서 갱신이 끊기면 전진이 차단되는지 확인한다.
- 가까운 장애물에서 후진·제자리 회전이 가능한지 확인한다.
- f를 한 번만 입력하고 추가 키 입력 없이 장애물을 접근시킨다. 정지 후 장애물을 치워도 새 f 명령 전에는 재출발하지 않아야 한다.

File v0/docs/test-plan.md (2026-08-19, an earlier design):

# v0 검증 순서

1. 배터리를 연결하지 않은 상태에서 ESP32와 TB6612FNG GND 공통을 확인한다.
2. `01_motor_test`를 업로드해 양쪽 모터의 전진·후진을 확인한다.
3. 방향이 반대면 모터 단자를 바꾸거나 코드의 방향을 반전한다.
4. `02_basic_drive`에서 `f`, `b`, `l`, `r`, `s` 명령을 시험한다.
5. 모터가 동작할 때 ESP32가 재부팅되면 5 V 전원과 470 uF 커패시터 배치를 점검한다.

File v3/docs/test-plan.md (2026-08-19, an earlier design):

# v3 검증 순서

1. BMI270 가속도·자이로 값을 시리얼 모니터에서 확인한다.
2. 조종기를 평평한 곳에 둔 뒤 중립 자세를 저장한다.
3. 손 기울기와 생성 명령값이 제스처 맵과 일치하는지 확인한다.
4. 낮은 속도에서 전진·후진·좌·우 제스처를 시험한다.
5. 정지 버튼, 통신 끊김, 전방 장애물 모두에서 차량이 정지하는지 확인한다.

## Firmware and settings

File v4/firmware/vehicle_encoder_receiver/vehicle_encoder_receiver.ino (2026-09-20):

// Arduino IDE 실습: C 문법 중심의 제어 로직. 라이브러리 호출은 Arduino C++ API.
#include <Arduino.h>
#include <stdbool.h>
#include <stdint.h>
#include <string.h>

// 필요 라이브러리: Pololu VL53L1X
// 좌우 N20 엔코더 모터 2개만 PID로 제어한다. 뒤쪽 두 바퀴는 수동 바퀴다.
// PULSES_PER_WHEEL_REV와 PID 계수는 사용하는 N20 엔코더에 맞춰 실측한다.
#include <WiFi.h>
#include <esp_now.h>
#include <Wire.h>
#include <VL53L1X.h>

const int IN1[2] = {18, 23};
const int IN2[2] = {19, 25};
const int PWM[2] = {13, 14};
const int ENC[2] = {34, 35};
const uint16_t STOP_MM = 200;
const float MAX_RPM = 100.0f;
const float PULSES_PER_WHEEL_REV = 1.0f;
const unsigned long PID_MS = 100;
float trim[2] = {1.00f, 1.00f};
float kp = 1.8f, ki = 0.40f, kd = 0.0f;

// 송신기와 수신기의 필드 순서·자료형을 동일하게 유지한다.
typedef struct {
  int16_t throttle;
  int16_t steering;
  bool emergencyStop;
  uint32_t sequence;
} ControlPacket;

ControlPacket latest = {0};
portMUX_TYPE dataMux = portMUX_INITIALIZER_UNLOCKED;
volatile unsigned long lastReceiveMs = 0;
volatile int32_t pulses[2] = {0, 0};
portMUX_TYPE pulseMux = portMUX_INITIALIZER_UNLOCKED;
VL53L1X tof;

void IRAM_ATTR encLeft(void) {
  portENTER_CRITICAL_ISR(&pulseMux);
  pulses[0]++;
  portEXIT_CRITICAL_ISR(&pulseMux);
}

void IRAM_ATTR encRight(void) {
  portENTER_CRITICAL_ISR(&pulseMux);
  pulses[1]++;
  portEXIT_CRITICAL_ISR(&pulseMux);
}

void setMotor(int i, int value) {
  digitalWrite(IN1[i], value > 0 ? HIGH : LOW);
  digitalWrite(IN2[i], value < 0 ? HIGH : LOW);
  analogWrite(PWM[i], constrain(abs(value), 0, 255));
}

float targetRpm[2] = {0, 0};
int direction[2] = {0, 0};
int32_t previous[2] = {0, 0};
float integral[2] = {0, 0};
float previousError[2] = {0, 0};
unsigned long lastPidMs = 0;

void stopAll(void) {
  for (int i = 0; i < 2; ++i) {
    setMotor(i, 0);
    targetRpm[i] = 0;
    direction[i] = 0;
    integral[i] = 0;
    previousError[i] = 0;
  }
}

void setSideTargets(int left, int right) {
  const int commands[2] = {left, right};
  for (int i = 0; i < 2; ++i) {
    direction[i] = commands[i] > 0 ? 1 : commands[i] < 0 ? -1 : 0;
    targetRpm[i] = abs(commands[i]) * MAX_RPM / 255.0f;
  }
}

void updatePid(void) {
  const unsigned long now = millis();
  if (now - lastPidMs < PID_MS)
    return;
  const float dt = (now - lastPidMs) / 1000.0f;
  lastPidMs = now;

  int32_t count[2];
  portENTER_CRITICAL(&pulseMux);
  for (int i = 0; i < 2; ++i)
    count[i] = pulses[i];
  portEXIT_CRITICAL(&pulseMux);

  for (int i = 0; i < 2; ++i) {
    const float rpm = (count[i] - previous[i]) * 60.0f /
                      (PULSES_PER_WHEEL_REV * dt);
    previous[i] = count[i];
    if (direction[i] == 0) {
      setMotor(i, 0);
      integral[i] = 0;
      previousError[i] = 0;
      continue;
    }
    const float error = targetRpm[i] - rpm;
    integral[i] = constrain(integral[i] + error * dt, -80.0f, 80.0f);
    const float derivative = (error - previousError[i]) / dt;
    const int pwm = constrain((kp * error + ki * integral[i] +
                               kd * derivative) * trim[i], 0, 255);
    setMotor(i, direction[i] * pwm);
    previousError[i] = error;
  }
}

// 새 측정이 준비됐을 때만 읽어 정지 명령·통신 시간 확인을 계속한다.
const unsigned long SENSOR_MAX_AGE_MS = 250;
uint16_t distanceMm = 0;
bool distanceValid = false;
unsigned long distanceReadMs = 0;

void updateDistance(void) {
  if (!tof.dataReady())
    return;
  distanceMm = tof.read(false);
  distanceValid = !tof.timeoutOccurred() && tof.last_status == 0 &&
                  tof.ranging_data.range_status == VL53L1X::RangeValid;
  distanceReadMs = millis();
}

bool obstacleTooClose(void) {
  return !distanceValid || millis() - distanceReadMs > SENSOR_MAX_AGE_MS ||
         distanceMm <= STOP_MM;
}

#if ESP_ARDUINO_VERSION_MAJOR >= 3
void onReceive(const esp_now_recv_info_t *source, const uint8_t *data, int len) {
#else
void onReceive(const uint8_t *source, const uint8_t *data, int len) {
#endif
  (void)source;
  if (len != sizeof(ControlPacket))
    return;
  portENTER_CRITICAL(&dataMux);
  memcpy(&latest, data, sizeof(latest));
  lastReceiveMs = millis();
  portEXIT_CRITICAL(&dataMux);
}

void setup(void) {
  for (int i = 0; i < 2; ++i) {
    pinMode(IN1[i], OUTPUT);
    pinMode(IN2[i], OUTPUT);
    pinMode(PWM[i], OUTPUT);
    pinMode(ENC[i], INPUT);
  }
  attachInterrupt(digitalPinToInterrupt(ENC[0]), encLeft, RISING);
  attachInterrupt(digitalPinToInterrupt(ENC[1]), encRight, RISING);
  stopAll();
  lastPidMs = millis();

  Wire.begin(21, 22);
  tof.setTimeout(500);
  if (!tof.init())
    while (true) {
      stopAll();
      delay(1000);
    }
  tof.setDistanceMode(VL53L1X::Long);
  tof.startContinuous(50);

  WiFi.mode(WIFI_STA);
  esp_now_init();
  esp_now_register_recv_cb(onReceive);
}

void loop(void) {
  updateDistance();
  ControlPacket packet;
  unsigned long receivedAt;
  portENTER_CRITICAL(&dataMux);
  packet = latest;
  receivedAt = lastReceiveMs;
  portEXIT_CRITICAL(&dataMux);

  if (millis() - receivedAt > 300 || packet.emergencyStop) {
    stopAll();
    return;
  }
  if (packet.throttle > 0 && obstacleTooClose()) {
    stopAll();
    return;
  }
  setSideTargets(constrain(packet.throttle + packet.steering, -255, 255),
                 constrain(packet.throttle - packet.steering, -255, 255));
  updatePid();
}

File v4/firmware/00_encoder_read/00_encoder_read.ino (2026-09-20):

// Arduino IDE 실습: C 문법 중심의 제어 로직. 라이브러리 호출은 Arduino C++ API.
#include <Arduino.h>
#include <stdint.h>

// 좌우 구동축의 N20 엔코더 A 채널 2개를 읽는 단품 확인 코드.
// 뒤쪽 두 바퀴는 수동 바퀴이므로 엔코더 입력을 연결하지 않는다.
// PULSES_PER_WHEEL_REV는 사용하는 N20 엔코더의 실제 출력축 값으로 바꾼다.

const int ENC_LEFT = 34;
const int ENC_RIGHT = 35;
const float PULSES_PER_WHEEL_REV = 1.0f; // 실측 후 수정
const unsigned long SAMPLE_MS = 500;

volatile int32_t pulses[2] = {0, 0};
portMUX_TYPE pulseMux = portMUX_INITIALIZER_UNLOCKED;

void IRAM_ATTR onLeft(void) {
  portENTER_CRITICAL_ISR(&pulseMux);
  pulses[0]++;
  portEXIT_CRITICAL_ISR(&pulseMux);
}

void IRAM_ATTR onRight(void) {
  portENTER_CRITICAL_ISR(&pulseMux);
  pulses[1]++;
  portEXIT_CRITICAL_ISR(&pulseMux);
}

unsigned long lastSample = 0;
int32_t previous[2] = {0, 0};

void setup(void) {
  Serial.begin(115200);
  const int encoderPins[2] = {ENC_LEFT, ENC_RIGHT};
  for (int i = 0; i < 2; ++i)
    pinMode(encoderPins[i], INPUT);

  attachInterrupt(digitalPinToInterrupt(ENC_LEFT), onLeft, RISING);
  attachInterrupt(digitalPinToInterrupt(ENC_RIGHT), onRight, RISING);
  Serial.println("LEFT,RIGHT encoder pulses and RPM");
}

void loop(void) {
  if (millis() - lastSample < SAMPLE_MS)
    return;
  lastSample = millis();

  int32_t now[2];
  portENTER_CRITICAL(&pulseMux);
  for (int i = 0; i < 2; ++i)
    now[i] = pulses[i];
  portEXIT_CRITICAL(&pulseMux);

  for (int i = 0; i < 2; ++i) {
    const int32_t delta = now[i] - previous[i];
    const float rpm = delta * 60000.0f / (PULSES_PER_WHEEL_REV * SAMPLE_MS);
    Serial.print(i == 0 ? "LEFT " : "RIGHT ");
    Serial.print(delta);
    Serial.print(" pulses / ");
    Serial.print(rpm, 1);
    Serial.print(" RPM");
    if (i == 0)
      Serial.print(" | ");
    previous[i] = now[i];
  }
  Serial.println();
}

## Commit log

2026-08-19 refactor: organize course materials by version
2026-08-19 docs: plan IMU and distance sensing expansions
2026-08-19 docs: define distance remote and gesture learning stages
2026-08-19 docs: add complete BOM setup and test guidance
2026-08-19 docs: centralize Arduino library guides
2026-08-19 docs: switch vehicle power to four AA batteries
2026-08-19 feat: add v4 encoder N20 PID drive
2026-08-19 docs: add ESP32 controller design references
2026-09-09 refactor: organize RC_CAR for teaching-only use
    [AA_4cell_holder_reference.stl, ESP32_DevKit_V1_reference.stl, M3_spacer_10mm_reference.stl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]
2026-09-09 refactor: teach RC_CAR with Arduino C-style sketches
2026-09-20 refactor: update RC car for dual drive and split power rails
2026-11-03 Add complete wiring and staged RC car practice sketches
2026-11-04 Add BMI270 tilt mode and complete RC wiring practices
2026-11-04 Add current hardware step-by-step drive practices
2026-11-07 Organize RC car firmware into v0-v4 practice stages
2026-11-09 docs: add v0-v4 pin map summary tables
2026-11-09 feat: add Ready motor and distance practice
